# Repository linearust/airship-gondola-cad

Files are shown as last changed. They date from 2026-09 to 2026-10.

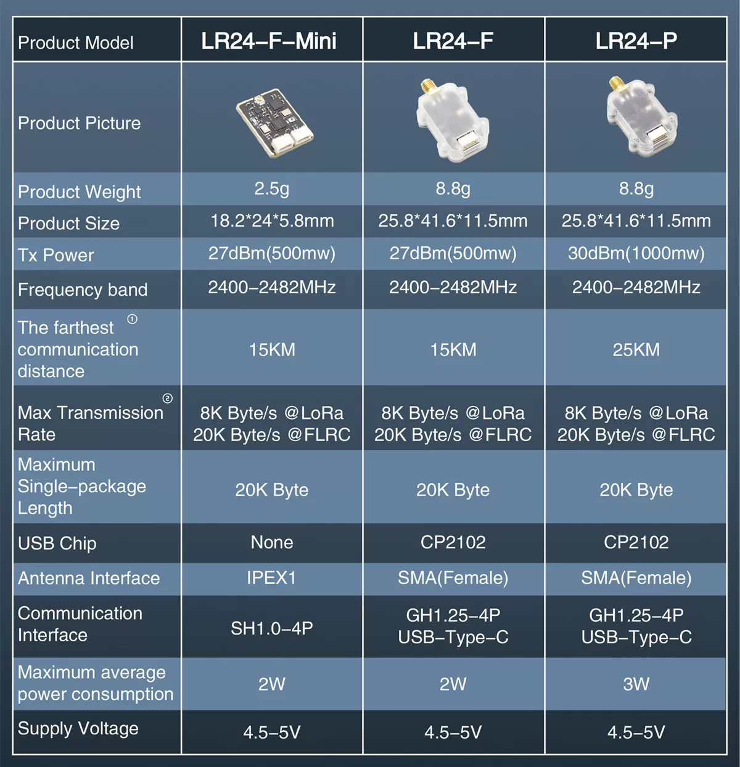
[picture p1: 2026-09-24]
references/lr24_specifications.webp

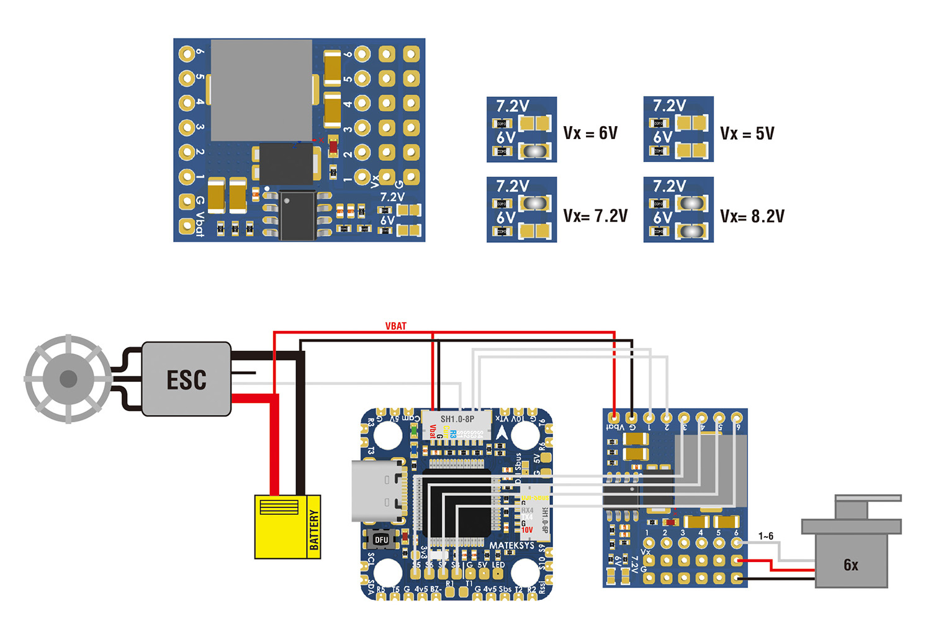
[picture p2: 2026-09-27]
references/matek_svpdb_8s_outputs.jpg

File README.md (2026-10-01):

# AI agent guide

Later user instructions take precedence. Inspect Git status and
`python3 -m gondola status` before editing; preserve unrelated edits and manual CAD.

## Design intent

- Favor low total mass and simple, printable, inspectable construction. Integrate
  parts unless assembly, motion or replacement benefits from separation.
- Prefer available metric parts, reusable interfaces and few fastener types.
  Accommodate fit variation without operating looseness or elaborate adjustment.
  Favor symmetric supports and snug located joints; nuts should insert freely
  while their pockets prevent rotation.
- Consider wiring, moving clearances, optical visibility and balance together.
  Improve existing geometry on merit, respecting confirmed purchases and intentional
  replaceable modules.

Scope: indoor LTA gondola, two independent tilt propulsors and onboard mounts;
fins and aft yaw hardware are excluded. Current manufacturing limits and selections
are in [design.py](gondola/contracts/design.py), not duplicated requirements here.

## State and evidence

[Contracts](gondola/contracts/), [parts](gondola/parts/) and
[assembly](gondola/assembly.py) define intended CAD, not measured hardware.
Read `release_status()` for unresolved interfaces. [Sources](references/sources.json)
index retained originals and dated user records. Distinguish source statements,
user confirmation, design allowances and measurements; resolve conflicts explicitly.
Preserve original evidence and provenance, not URLs alone. Keep changing dimensions
and generated inspection sheets out of maintained prose.

[Verification](references/design_verification.json) records a past execution, valid
only for its inputs. `source_fingerprint()` covers Python under `gondola`, root
macros and `gondola/data`; tests, tools and documents need separate change/hash checks.
CAD success does not establish physical fit, strength, creep, adhesion, wiring,
power, installed mass/CG or flight readiness. Qualify coupons using production
material, process, finish and feature orientation.

## Workflow

Update affected geometry, native controls/parents, interfaces, BOMs and motion/service
checks together. Review full travel and ordered removal; distinguish sampled from
continuous checks. Fixture replacement requires independent old/new shape, placement,
control and metadata review, never merely a new checksum to hide a failure.

Documentation-only changes: check links, JSON, source records and `git diff --check`.
Code changes: Ruff and relevant tests. CAD release: native FreeCAD unittest discovery
with no skips for `tests`, `tools/blender_review` and `tools/simulation`.
[Runtime launcher](gondola/freecad_runtime.py) locates the AppImage; use its
`AppRun python` with repository and `usr/lib` in `PYTHONPATH`.

Freeze source; run in order and stop on failure:

```sh
python3 -m gondola build
python3 -m gondola preview
python3 -m gondola compare
python3 -m gondola validate
python3 -m gondola bundle
python3 tools/blender_review/run.py --render-stills
python3 tools/simulation/export_parameters.py
```

`build/` is generated/ignored. Preview saves CAD, so it precedes file-bound checks.
Inspect assembly, print layout and affected views. For `gondola`, `--output-dir PATH`
precedes the subcommand; keep output/source paths consistent across tools. Export manifest-listed
parts, distinguish optional power parts, and retain hash-bound verification.

Optional paired rail/frame/saddle fit specimen: after validation, run
`python3 tools/fit_coupon/export_joint.py --output-dir PATH` with a new directory.
It crops saved production geometry; it is outside the installed BOM/print bundle
and tests local fit, not whole-frame strength or complete-assembly tool access.

Blender checks prescribed rigid motion, not dynamics or flexible wires. Simulation
geometry is exported to `build/simulation_parameters.json`; unknowns remain unset.
Native coordinates are not CV/CG or FRD. Recheck hashes before presenting artifacts.

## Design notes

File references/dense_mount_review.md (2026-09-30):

# Mounting interface source map

Plate geometry and permitted patterns are defined in
[mounting_plate.py](../gondola/parts/mounting_plate.py) and
[mounting_slots.py](../gondola/parts/mounting_slots.py); carrier support and
adhesive allocations are in [equipment_mounts.py](../gondola/parts/equipment_mounts.py).
Use the contracts and their checks when changing an occupied mount. This project
array is not a universal industry standard or a drop-in X500 interface.

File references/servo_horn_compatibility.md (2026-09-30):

# Horn source map

The [manufacturer provenance record](manufacturer/kst_x06_servo_horns_2026-09-28.json)
identifies the user-supplied archive, retained STEP, units and coordinate transform.
These are nominal source geometry, not measurements of a received horn.

Current selection and hole preparation belong to
[servo_horns.py](../gondola/contracts/servo_horns.py); adapter geometry and fit
allowances to [servo_coupling.py](../gondola/parts/servo_coupling.py).
Use [servo_module.py](../gondola/validation/servo_module.py) and
[horn_coupling.py](../gondola/validation/horn_coupling.py) for ordered
service checks.

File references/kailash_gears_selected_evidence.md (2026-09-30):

# Retained Kailash seller statements

Transcription from user-supplied saved AliExpress pages and dimension images.
The full product pages are not retained in this repository; this is seller
source evidence, not independent certification or a received-part measurement.
The [2026-09-29 cart](cart_selected_parts_2026-09-29.json) separately preserves
selected options and quantities. Links identify provenance, not live availability.

| Recorded item | 48T | 16T |
| --- | --- | --- |
| Listing | [HDAA-05](https://www.aliexpress.com/item/1005011637445325.html) | [XC05-S1](https://www.aliexpress.com/item/1005013121105173.html) |
| Selected option | 48 teeth / 3 mm | 16 teeth / 3 mm |
| Module / pressure angle | 0.5 / 20° | 0.5 / 20° |
| Tooth type / process stated | External spur / hobbing | External spur / hobbing |
| Pitch / outside diameter | 24 / 25 mm | 8 / 9 mm |
| Face width / total length | 3 / 8 mm | 5 / 10 mm |
| Hub diameter / extension beyond teeth | 12 / 5 mm | 6.5 / 5 mm |
| Plain bore | Ø3 mm; H8 stated | Ø3 mm; tolerance not stated |
| Radial screw thread | M3 | M3 |
| Screw axis from hub end | Not stated | 2.5 mm |
| Material wording | Aluminium alloy in description; alloy steel in attribute | Copper/copper alloy; exact alloy unspecified |

The page's 38.7 g example refers to 130T, not 48T. No measured masses, screw
inclusion, length, point or tightening torque are established by this record.
The 16T axial screw position must not be inferred for the 48T gear.

Retained source images: [section](kailash_16t_dimensions.png) and
[size table](kailash_16t_table.png). The section is generic; the 16T row gives
C=8, D=9 and G=6.5 mm. [Source index](sources.json) binds their retained bytes.
Current CAD interpretation belongs to [drive.py](../gondola/contracts/drive.py).

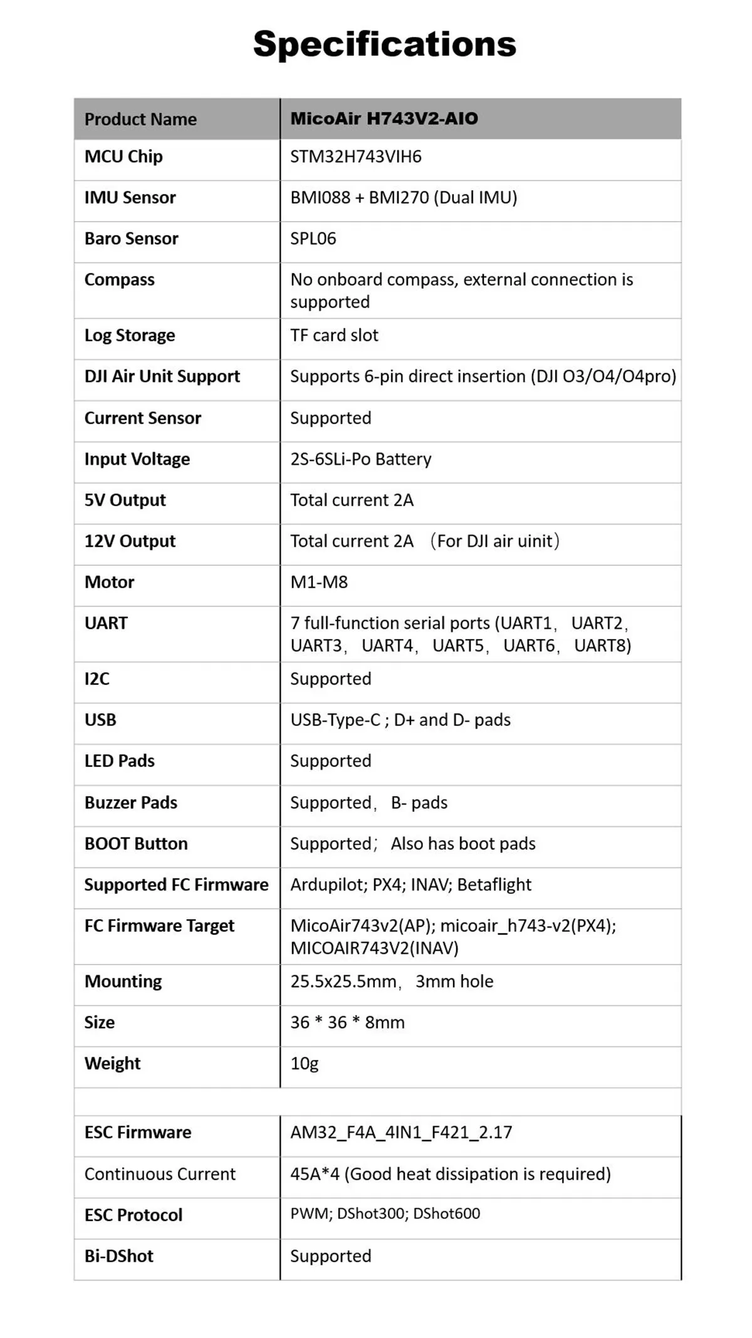
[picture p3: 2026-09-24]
references/micoair743v2_aio45a_specifications.webp

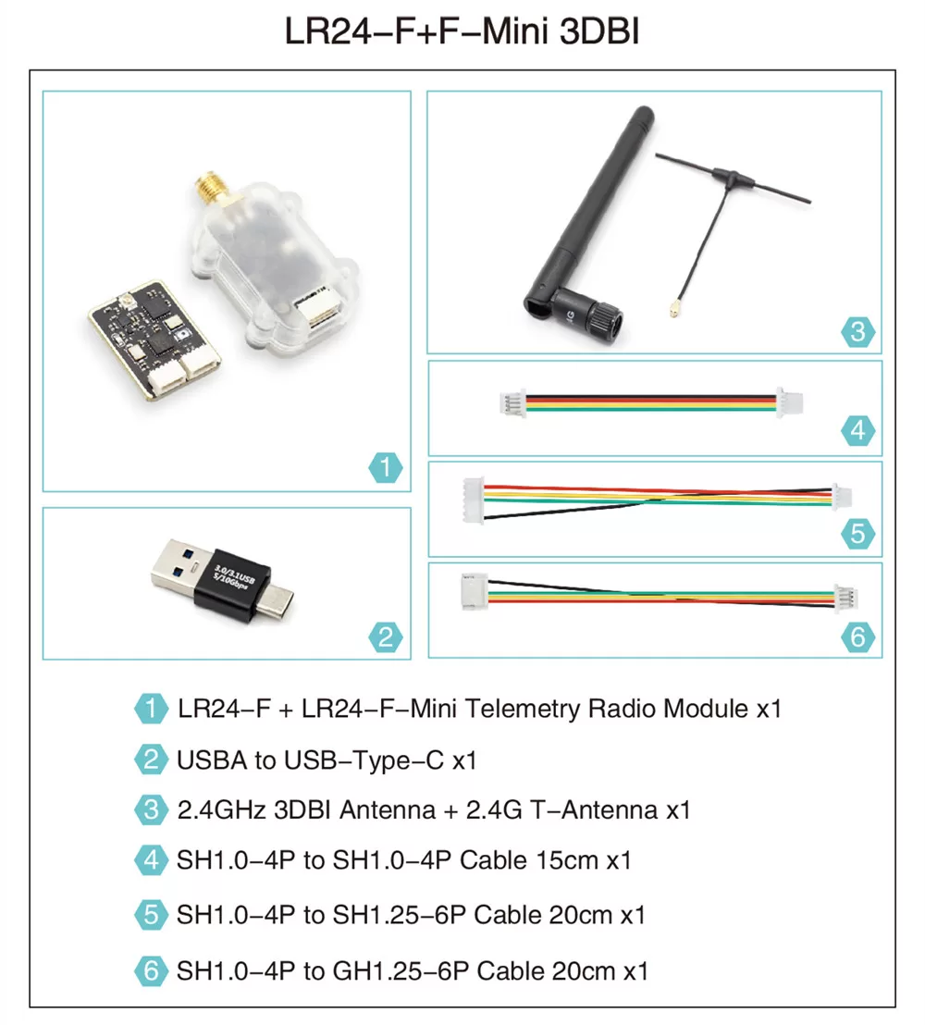
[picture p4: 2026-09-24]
references/lr24f_mini_package.webp

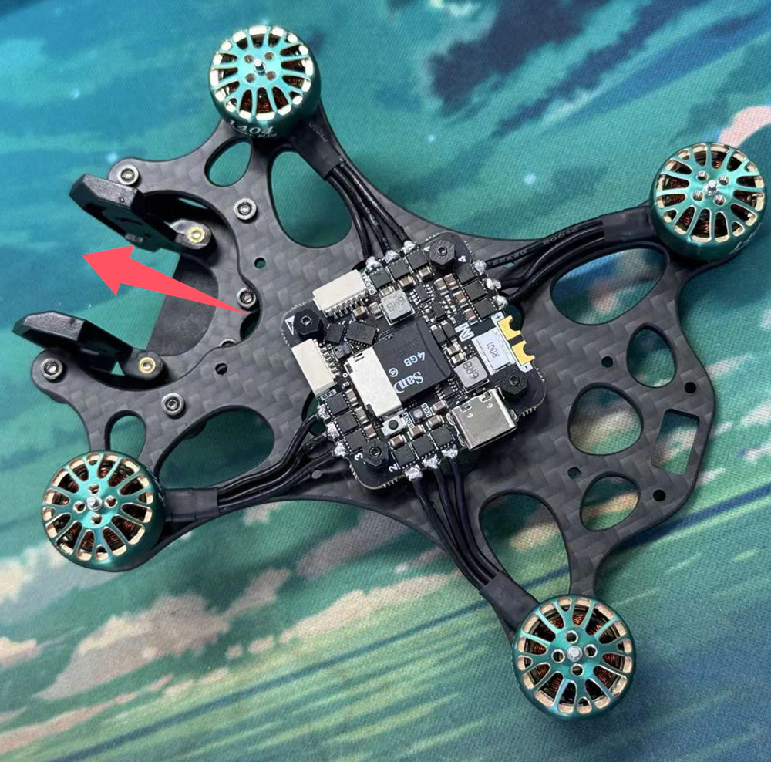
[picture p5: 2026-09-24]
references/micoair743v2_aio45a_orientation.webp

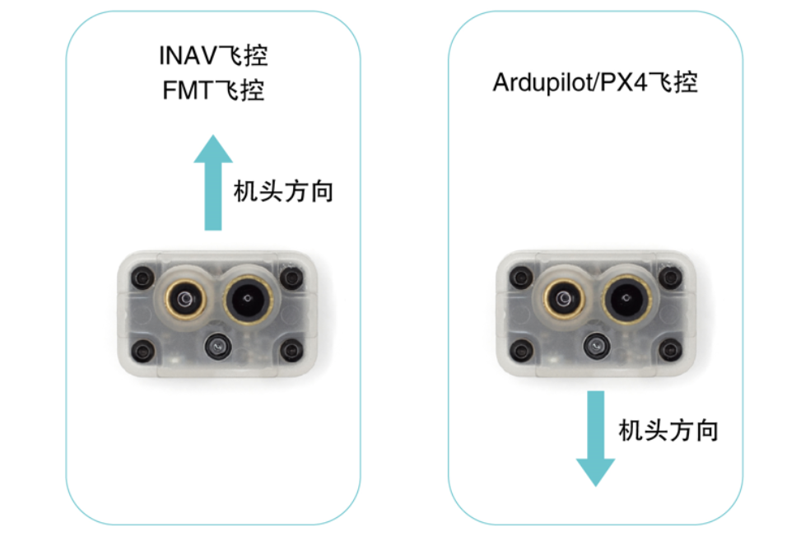
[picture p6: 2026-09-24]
references/mtf01p_orientation.webp

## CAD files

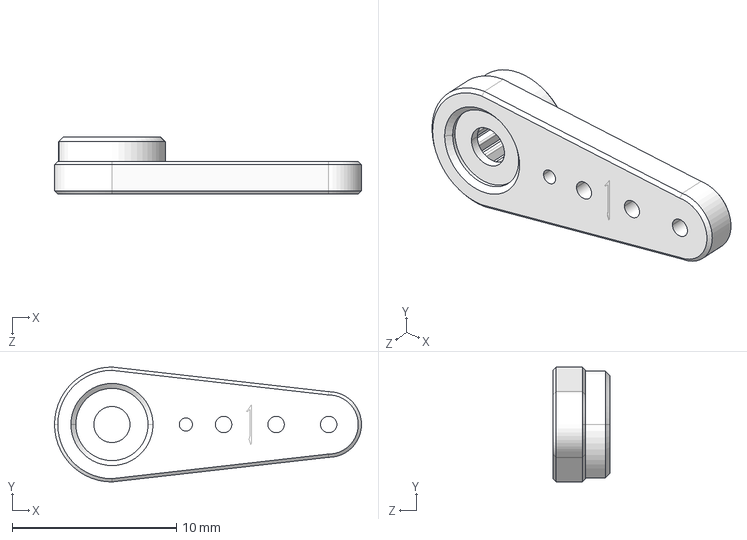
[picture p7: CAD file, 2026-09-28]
gondola/data/kst_x06_half_arm_1.step
18.7 x 7.00 x 3.50 mm

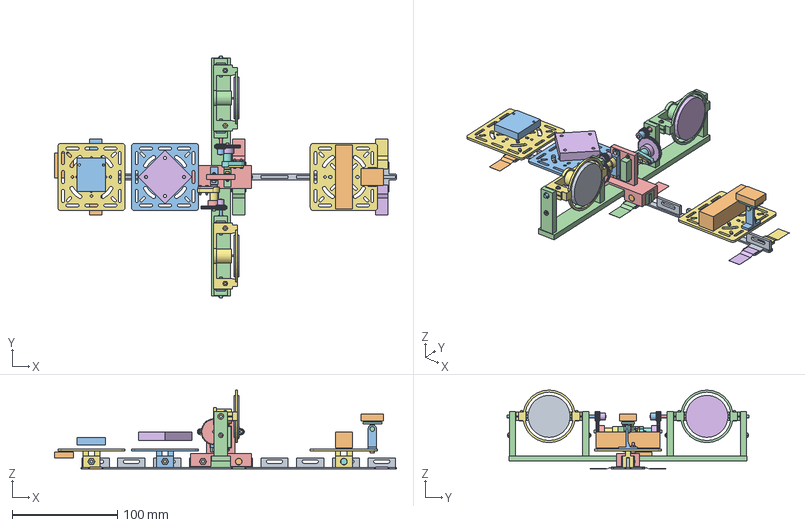
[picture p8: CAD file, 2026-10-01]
tests/fixtures/geometry.FCStd
325.1 x 230.0 x 75.0 mm
SLS/MJF | PA12 unfilled | PRINT | side-slot rail 300mm
REFERENCE | optional single-sided tape over wing
REFERENCE | optional single-sided tape over wing001
REFERENCE | optional single-sided tape over wing002
REFERENCE | optional single-sided tape over wing003
REFERENCE | optional single-sided tape over wing004
REFERENCE | optional single-sided tape over wing005
SLS/MJF | PA12 unfilled | PRINT | OpticalSensorTray
BUY | manual optical pitch nut
MTF-02P | independently leveled optical face
SLS/MJF | PA12 unfilled | PRINT | OpticalMountBase
BUY | manual optical pitch bolt
BUY | optical carrier foot 2 bolt
BUY | optical carrier foot 2 nut
SLS/MJF | PA12 unfilled | PRINT | Universal carrier | battery
BUY | M3 x10 recessed side rail bolt | design head envelope
BUY | M3 rail hex nut | blind pocket on a printed bearing floor
REFERENCE | provisional2S battery, long axisY
SLS/MJF | PA12 unfilled | PRINT | Universal carrier | electronics
BUY | M3 x10 recessed side rail bolt | design head envelope001
BUY | M3 rail hex nut | blind pocket on a printed bearing floor003
REFERENCE | MicoAir743v2-AIO-45A
SLS/MJF | PA12 unfilled | PRINT | Universal carrier | accessory
BUY | M3 x10 recessed side rail bolt | design head envelope002
BUY | M3 rail hex nut | blind pocket on a printed bearing floor004
REFERENCE | LR24-F-Mini | onboard radio
REFERENCE | LinkTrack P-AS | interchangeable navigation slot
SLS/MJF | PA12 unfilled | PRINT | PropulsionFixedFrame
SLS/MJF | PA12 unfilled | PRINT | ServoDriveBridge
BUY | PortDriverGear
BUY | PortServoHorn
SLS/MJF | PA12 unfilled | PRINT | PortHornGearAdapter
BUY | PortHornGearClampNearBolt
BUY | PortHornGearClampNearNut
BUY | PortHornGearClampFarBolt
BUY | PortHornGearClampFarNut
BUY | PortInputShaft
BUY | PortInputShaftClampBolt
BUY | PortInputShaftClampNut
BUY | PortServoEarLowerBolt
BUY | PortServoEarLowerNut
BUY | PortServoEarUpperBolt
BUY | PortServoEarUpperNut
KST X06 V6.0 vertical case 20×7×16.6; 6 g
BUY | StarboardDriverGear
BUY | StarboardServoHorn
SLS/MJF | PA12 unfilled | PRINT | StarboardHornGearAdapter
BUY | StarboardHornGearClampNearBolt
BUY | StarboardHornGearClampNearNut
BUY | StarboardHornGearClampFarBolt
BUY | StarboardHornGearClampFarNut
BUY | StarboardInputShaft
BUY | StarboardInputShaftClampBolt
BUY | StarboardInputShaftClampNut
BUY | StarboardServoEarLowerBolt
BUY | StarboardServoEarLowerNut
BUY | StarboardServoEarUpperBolt
BUY | StarboardServoEarUpperNut
KST X06 V6.0 vertical case 20×7×16.6; 6 g001
SLS/MJF | PA12 unfilled | PRINT | PortMotorCarrier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

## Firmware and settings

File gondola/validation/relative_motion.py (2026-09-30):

"""Continuous separation of installed solids belonging to different tilt groups."""

import math

from gondola.cad import belongs_to_group, world_shape
from gondola.contracts import servo_horns
from gondola.contracts.design import MODULE_STATIONS
from gondola.contracts.drive import drive_for_document

from .geometry import intersection_volume
from .rotation_envelope import full_orbit_envelope

MINIMUM_GAP_MM = 0.1
TOL = 1e-7


def _input_drive_membership(parts):
    """Require the selected metal-stub mechanism to share each input motion."""
    suffixes = (
        "ServoHorn",
        "DriverGear",
        "HornGearAdapter",
        "HornGearClampNearBolt",
        "HornGearClampFarBolt",
        "InputShaft",
        "InputShaftClampBolt",
        "InputShaftClampNut",
    )
    rows = []
    for prefix in ("Port", "Starboard"):
        expected = {prefix + suffix for suffix in suffixes}
        if not servo_horns.profile(side=prefix).threaded:
            expected.update(
                prefix + "HornGearClamp" + side + "Nut" for side in ("Near", "Far")
            )
        actual = {
            part["name"] for part in parts if part["group"] == prefix + "InputDrive"
        }
        rows.append(
            {
                "group": prefix + "InputDrive",
                "expected_parts": sorted(expected),
                "actual_parts": sorted(actual),
                "passed": actual == expected,
            }
        )
    return rows


def _static_expression_contract(doc, spec):
    """Allow only the source architecture's closed, manual-control dependencies.

    The four tilt formulas are the only expressions depending on the pod motion.
    Every other permitted formula reads literal manual properties. Inspecting
    *all* expression engines also rejects an expression added to one of those
    input properties, an intervening group, or an indirect helper object. A
    finite pose probe cannot establish this absence of nonlinear dependence.
    Static placements without expressions remain valid, including a moved root.
    """
    allowed = {}
    for station in MODULE_STATIONS:
        allowed[station.object_name] = {
            "Placement.Base.x": "RailPositionX",
        }
    allowed["OpticalFlowModule"] = {
        "Placement.Base.x": "MountSide==0?27mm:-27mm",
        "Placement.Rotation.Angle": "MountSide==0?0deg:180deg",
    }
    for prefix in ("Port", "Starboard"):
        allowed[prefix + "Pod"] = {
            "Placement.Rotation.Angle": "min(MaximumTilt;max(MinimumTilt;Tilt))"
        }
        allowed[prefix + "InputDrive"] = {
            "Placement.Rotation.Angle": f"-{prefix}Pod.Placement.Rotation.Angle/{spec.ratio:g}"
        }
    for coordinate in ("Roll", "Pitch"):
        allowed["Optical" + coordinate + "Stage"] = {
            "Placement.Rotation.Angle": f"min(MaximumAngle;max(MinimumAngle;{coordinate}))"
        }
    allowed["ModuleBatteryEnvelope"] = {
        "Placement.Base.x": "CentreX-(Length*cos(InPlaneRotation)-Width*sin(InPlaneRotation))/2",
        "Placement.Base.y": "CentreY-(Length*sin(InPlaneRotation)+Width*cos(InPlaneRotation))/2",
        "Placement.Base.z": "BottomZ",
        "Placement.Rotation.Angle": "InPlaneRotation",
    }
    count = 0
    for obj in doc.Objects:
        for path, expression in getattr(obj, "ExpressionEngine", ()):
            path = path.lstrip(".")
            if allowed.get(obj.Name, {}).get(path) != "".join(expression.split()):
                raise ValueError(
                    "Native motion expression contract rejects " + obj.Name + "." + path
                )
            count += 1
    return {
        "checked_expression_count": count,
        "scope": "Closed source expression allowlist across every native object. Additional expressions on manual controls, child features, intervening groups or indirect helper properties are rejected; static placements are allowed.",
        "passed": True,
    }


def _gap(first, second):
    return max(first[0] - second[1], second[0] - first[1], 0.0)


def _part(shape, name, *, group="Fixed", prefix="", axis=(0, 0, 0), rate=0.0):
    bounds = shape.BoundBox
    limits = [
        (bounds.XMin, bounds.XMax),
        (bounds.YMin, bounds.YMax),
        (bounds.ZMin, bounds.ZMax),
    ]
    envelope, radius, orbit = shape, 0.0, limits
    if rate:
        envelope, evidence = full_orbit_envelope(shape, axis)
        radius = evidence["radius_mm"]
        orbit = [
            (axis[0] - radius, axis[0] + radius),
            limits[1],
            (axis[2] - radius, axis[2] + radius),
        ]
    return dict(
        shape=shape,
        name=name,
        group=group,
        prefix=prefix,
        axis=axis,
        rate=rate,
        bounds=limits,
        envelope=envelope,
        radius=radius,
        orbit=orbit,
    )
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

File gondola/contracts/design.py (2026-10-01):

"""User decisions and unresolved interfaces consumed by CAD and the CLI.

Part geometry belongs to gondola/parts; published interface dimensions belong to
the other contract modules. Geometric test success never changes release status.
"""

import math
from collections import Counter
from dataclasses import asdict, dataclass
from numbers import Real

from .drive import SELECTED_DRIVE
from .equipment_interfaces import (
    FC_ELECTRICAL_EVIDENCE,
    FC_LISTED_MASS_G,
    FC_MODEL,
    X06_DATASHEET_SOURCE,
    X06_MANUFACTURER_SOURCE,
    flight_controller_contract,
)
from .equipment_options import get_navigation_profile, get_radio_profile
from .fasteners import KIT_MATERIAL, RAIL_FASTENER_MATERIAL
from .optical_sensors import get_sensor_profile
from .power_options import power_option_contract
from .rail_attachments import module_attachment_pattern
from .servo_horns import SELECTED_BY_SIDE
from .servo_horns import profile as horn_profile

CREALLO_GUIDE_URL = "https://creallo.com/ko/guide/design-spec-guide"
DESIGN_REVISION = "BY"
# Nominal local part dimensions, before print rotation; not delivered-size tolerance.
MAX_PRINT_PART_DIMENSION_MM = 340.0
# Chosen assembly length is independent of the supplier-screening size limit.
RAIL_LENGTH_MM = 300.0
# User's 2026-09-29 manufacturing review requires at least this nominal rail
# attachment thickness; actual delivered dimensions/curvature remain unmeasured.
RAIL_BASE_THICKNESS_MM = 1.5
# Project structural interface, independent of the FC mounting-hole pattern.
STACK_PITCH_MM = 45.0
STACK_ANCHOR_CENTRES = tuple(
    (sign * STACK_PITCH_MM / 2, sign * STACK_PITCH_MM / 2) for sign in (-1, 1)
)
STACK_ANCHOR_LOCATIONS = (
    " and ".join(f"({x:g}, {y:g})" for x, y in STACK_ANCHOR_CENTRES) + " mm"
)
PUBLISHED_PROCESS_SIZE_MM = {"SLS": [340, 340, 600], "MJF": [380, 380, 280]}
MANUFACTURING_DECISION = {
    "reviewed_on": "2026-09-30",
    "supplier": "Creallo",
    "material": "Unfilled PA12 design basis; supplier grade/process/finish agreement pending. Do not substitute fibre-filled grades without redesign and renewed flexure qualification.",
    "preferred_process": None,
    "candidate_processes": ["SLS", "MJF"],
    "maximum_nominal_part_dimension_mm": MAX_PRINT_PART_DIMENSION_MM,
    "part_size_rule": f"Each local part bounding-box dimension before print rotation and each oriented export dimension must be at most {MAX_PRINT_PART_DIMENSION_MM:g} mm. Apply to every installed print and coupon; additionally screen oriented exports against both published process envelopes. This nominal CAD limit is not a guarantee of delivered dimensions.",
    "nominal_rail_length_mm": RAIL_LENGTH_MM,
    "rationale": "PA12 is Creallo's documented functional powder-bed nylon and suits open integral supports and the rail flexure trial. Neither SLS nor MJF is established as superior for this assembly; choose with the supplier using fit, stiffness, straightness and mass requirements. A material/process change requires renewed fit and flexure qualification.",
    "supplier_process_policy": "Creallo integrates SLS/MJF quotations and selects the process unless separately agreed. No process is preselected here. Confirm the actual PA12 grade, process and finish before printing matched coupons and full parts.",
    "size_guide_scope": "Published maximum fabrication sizes include split-and-join manufacture. They are screening bounds, not guaranteed one-piece machine capacity or acceptance.",
    "qualification": "Not qualified: obtain one-piece acceptance and review rail flexures, straightness, curvature, fatigue and seated mounting fit. Use the same agreed unfilled PA12 process/material/finish and corresponding feature orientation for coupons and full parts. Verify the optical carrier foot and pitch seat for flatness, pointing stability and creep with actual fasteners.",
    "nominal_general_functional_wall_mm": 1.5,
    "nominal_rail_flexure_mm": RAIL_BASE_THICKNESS_MM,
    "flexure_exception": "The straight rail base and tape wings retain the user-reported manufacturing-review minimum of1.5mm nominal. Nine identical26mm walls on34mm centres leave8mm gaps above the continuous rail base. The16mm carrier feet retain full-foot travel of +/-4.2mm. The continuous58mm propulsion spine seats on adjacent walls;15.4mm slots permit +/-6mm paired trim with12mm centred load zones and at least19mm support per wall/45mm combined. The9walls retain5.3mm slot-end ligaments. Actual thickness, bonded curvature, tape retention, stiffness and fatigue remain unqualified; use the rail contract for exact intervals.",
    "dfam_basis": "Prefer simple integral load-bearing sections and accessible through-features. Retain openings for assembly, wiring or motion; omit lightening windows that leave fragile narrow ligaments for negligible system-level benefit. SLS/MJF powder supports overhangs; do not introduce splits solely from FDM/SLA support-angle rules. Keep powder-removal access to holes and pockets. Do not add lattice infill or sealed hollow regions; avoid extra fine struts and trapped powder.",
    "sources": {
        "dimensions_and_tolerances": CREALLO_GUIDE_URL,
        "process_policy": "https://creallo.com/ko/blog/posts/sls-mjf-integration-update",
        "process_capability": "https://creallo.com/ko/capability/process/3DP/SLS",
        "pa12_material": "https://creallo.com/ko/capability/material/SLS/SLSPA12",
        "design_guide": "https://creallo.com/ko/guide/3d-printing-design-guide",
        "lattice_and_powder_removal": "https://creallo.com/ko/guide/lattice-structure-3d-printing-dfam",
    },
}
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

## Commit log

2026-09-20 Refactor gondola CAD workflow and enforce artifact consistency
    Keep source, primary dimensional evidence and a pinned regression fixture; remove legacy generated trees. Consolidate part modules, CAD helpers, artifact hashing and schema definitions.
    Require current preview, saved-CAD validation and frozen-baseline comparison before packaging. Fix asynchronous preview failures, BOM evidence grouping and STL surface comparison across equivalent triangulations.
    Validated with 43 offline tests, Ruff and FreeCAD 1.1.3: full build/preview/validate/compare/bundle succeeds; all 90 baseline shapes and native controls are preserved.
    [rev_i_geometry.FCStd]
2026-09-20 Document procurement checklist for the current gondola assembly
    Record hardware specifications and installed quantities, onboard equipment, consumables and tools. Preserve unresolved OEM interfaces and require agents to synchronize the checklist with validated BO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
2026-09-20 Shorten rail to 340 mm for Creallo PA12 SLS prototype
    [design_contract.py]
2026-09-20 Lighten gondola with M2 hardware and add MTF-02P
    [rev_i_geometry.FCStd, rev_k_geometry.FCStd]
2026-09-20 Replace stacked boards with compact verified mounting interfaces
    [rev_k_geometry.FCStd, rev_l_geometry.FCStd]
2026-09-21 Fix journal retention and verify CAD procurement integrity
    [rev_l_geometry.FCStd, rev_m_geometry.FCStd]
2026-09-21 Reserve practical wiring access with minimal carrier changes
    [rev_m_geometry.FCStd, rev_n_geometry.FCStd]
2026-09-21 Add interchangeable optical sensor stack with verified clearances
    [rev_n_geometry.FCStd, rev_o_geometry.FCStd]
2026-09-21 Simplify ultralight gondola hardware and printed supports
    [rev_o_geometry.FCStd, rev_p_geometry.FCStd]
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2026-09-21 Organize design contracts and clarify CAD module naming
2026-09-21 Implement independent X06 geared tilt modules
    [rev_p_geometry.FCStd, rev_q_geometry.FCStd]
2026-09-21 Refactor propulsion builders and validation responsibilities
    Split geared propulsion assembly and audits into focused helpers while
    preserving native geometry, object order, metadata and motion expressions.
    Move portable purchasing specifications and manufacturing checks to their
    own modules, and keep malformed known specifications fail-closed.
    Retain the reviewed Rev Q fixture and all nominal dimensions, hardware
    quantities, mass accounting and manufacturing qualification limits.
2026-09-21 Improve connector access and centralize wiring checks
    Expand the FC peripheral allowance to 9 mm, move LR900 and P-AS 6 mm
    outward, and use a shared 44 mm structural stack. Add 2 mm side/top
    handling allowances to the radio and UWB connector lanes and relocate
    the XT30 allocation. Printed mass increases by 0.288 g with no change
    to purchased part types or quantities.
    Centralize wiring geometry and minimum-gap checks. Check tilted optical
    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
    [rev_q_geometry.FCStd, rev_r_geometry.FCStd]
2026-09-21 Support interchangeable tilt gears with a shared radial input mount
    Keep the 60/20 drive as default and support the sourced 64/20 alternative
    using the same printed frame, input supports, shafts and fastener inventory.
    Bind gear identity, native motion, placement, procurement and validation to
    one finite drive contract; retain explicit limits on clamp retention.
    Audit and pin the Rev S geometry transition. Verify cartridge adjustment,
    functional walls, and prerequisite-aware bearing-cap service. Distinguish
    STEP scalar integration drift from actual solid changes through bilateral
    empty-topology checks while retaining strict bounds and difference gates.
    [rev_r_geometry.FCStd, rev_s_geometry.FCStd]
2026-09-22 Refactor propulsion contracts and tighten print geometry validation
    Centralize required propulsion evidence so omitted checks cannot lower their
    own expected counts and a successful parent cannot hide failed rows. Remove
    unused constants, reuse the output-axis spacing, and derive manufacturing
    probes from the saved drive configuration.
    Use one print-solid identity gate for STEP round trips and repeated parts.
    Reject loose point, edge or face topology while allowing single-solid
    container wrappers and the verified empty-cut volume-integral exception.
    Validated with Ruff, 183 native tests (zero skips), full 60/20 and64/20
    assembly/equipment audits, and the unchanged151-shape RevS baseline.
    D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
2026-09-22 Replace adjustable gear mounts with fixed interchangeable supports
    Use round mounting holes and gear-specific 60T/64T input supports in the common frame. Remove the radial-slide travel and live mesh-adjustment controls; keep the servo cradle and bearing seats integral while retaining the detachable support needed for assembly and service.
    Validate the fixed datum, matching support identity and circular-hole geometry, including negative tamper tests. Preserve existing shaft, fastener, electronics, optical and rail geometry. Correct the lower horn-clamp extraction path for the 64T support and continuously check both sides of both configurations. Update the AI-agent contract and reviewed RevT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
    [rev_s_geometry.FCStd, rev_t_geometry.FCStd]
2026-09-22 Simplify propulsion to direct servo gears on an integral frame
    Replace input cartridges, shafts and bearings with bought KST horns and compact direct gear adapters. Integrate open-sided servo saddles into the fixed frame and use 7 mm bore driver gears. Preserve supported output stubs and ordered service access.
    Audit and pin Rev U geometry, update procurement and estimated mass, and validate both gear configurations. All 187 native tests and the build, preview, validate, compare and bundle workflow pass. Servo radial loading and physical adapter fit remain prototype qualification items.
    [rev_t_geometry.FCStd, rev_u_geometry.FCStd]
2026-09-22 Make servo gear drives replaceable on a common frame
    [rev_u_geometry.FCStd, rev_v_geometry.FCStd]
2026-09-22 Increase tilt fastener clearance and validate continuous motion
    [rev_v_geometry.FCStd, rev_w_geometry.FCStd]
2026-09-22 Strengthen replaceable servo holders with paired side walls
    [rev_w_geometry.FCStd, rev_x_geometry.FCStd]
2026-09-22 Make PA12 process selection neutral and enforce print part size limits
    [rev_x_geometry.FCStd, rev_y_geometry.FCStd]
2026-09-22 Integrate servo supports and simplify bearing retainers
    [rev_y_geometry.FCStd, rev_z_geometry.FCStd]
2026-09-22 Separate paired servo drive for replacement
    [rev_aa_geometry.FCStd, rev_z_geometry.FCStd]
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2026-09-22 Adapt gondola to selected cart gears, shafts and M2 hardware
    Use the supplied 48T/16T module-0.5 gear dimensions and both 3 mm
    bores. Couple the drivers through prepared metal input stubs, retain
    a removable paired-servo module, and account for asymmetric gear widths.
    Replace square-nut/headless rail clamps with the selected M2 button
    screws and hex nuts, including full release/tool access. Record the
    6061 rod cut list, generic bearing selection, exclusions and unverified
    received-part interfaces. Audit and pin revision AB geometry.
    [rev_aa_geometry.FCStd, rev_ab_geometry.FCStd]
2026-09-22 Refactor purchase metadata and propulsion service checks
    Share purchase field definitions across native CAD annotations and BOM
    exports. Read gear and fastener constants from their source contracts,
    make selected hardware materials explicit, and synchronize CAD scope
    exclusions with the selected equipment contract.
    Consolidate the input-drive part inventory and service-path dispatch
    without changing validation thresholds, evidence, or part geometry.
    Clarify the AI README and selected-hardware documentation.
    Validation: all 254 native FreeCAD tests pass without skips. Full saved-CAD
    validation, comparison of all 130 shapes against the unchanged AB fixture,
    and current-source prototype bundl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
    [design.py]
2026-09-23 Integrate optical tower and relax nonlocating fit envelopes
    [rev_ab_geometry.FCStd, rev_ac_geometry.FCStd]
2026-09-23 Replace optical tower fasteners with integral PA12 latches
    [rev_ac_geometry.FCStd, rev_ad_geometry.FCStd]
2026-09-23 Simplify bearing supports and reinforce optical pivots
    [rev_ad_geometry.FCStd, rev_ae_geometry.FCStd]
2026-09-23 Fix optical tower seating and audit servo horn clearance
    [rev_ae_geometry.FCStd, rev_af_geometry.FCStd]
2026-09-23 Simplify bearing and horn retention in revision AG
    Replace four printed bearing caps and their fasteners with inward-loaded cups,
    integral outer shoulders and four purchased inner-ring spacers. Remove the two
    horn backstraps using prepared stock horn tips and shared M1.6 fasteners.
    Preserve the removable paired servo drive and all selected gear/shaft sizes.
    Add capture, complete-rotor motion and staged service checks, document the new
    purchases and horn preparation, and audit the intentional fixture transition.
    Installed prints decrease from 18 to 12; modeled installed pieces from 84 to 74.
    Validation: 276 native tests without skips, 7 procurement tests after wording
    cleanup, final saved-C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
    [rev_af_geometry.FCStd, rev_ag_geometry.FCStd]
2026-09-23 Strengthen rail clamp and simplify bearing-post roots in AH
    [rev_ag_geometry.FCStd, rev_ah_geometry.FCStd]
2026-09-23 Simplify optical base and paired servo support in AI
    [rev_ah_geometry.FCStd, rev_ai_geometry.FCStd]
2026-09-23 Tighten rail fit and consolidate servo supports in AJ
    [rev_ai_geometry.FCStd, rev_aj_geometry.FCStd]
2026-09-23 Simplify horn adapters, servo bridge and P-AS support
    [rev_aj_geometry.FCStd, rev_ak_geometry.FCStd]
2026-09-23 Refactor shared propulsion service checks
    Separate removal paths and retained-obstacle collection from report coordination, removing circular validation imports. Reuse the common shape translation helper and remove unused horn helpers and constants.
    Validation: 311 native tests passed with no skips; build, preview, validate, compare and bundle passed. All 117 shapes, placements, native controls and interface metadata match the unchanged AK fixture. BOM and design metrics are unchanged.
2026-09-23 Reinforce optical pivot link and verify input nut capture
    [rev_ak_geometry.FCStd, rev_al_geometry.FCStd]
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2026-09-23 Remove bearing spacers and adapt drive to supplied servo horns
    [rev_al_geometry.FCStd, rev_am_geometry.FCStd]
2026-09-23 Refactor servo interfaces and correct bearing travel checks
    [equipment_interfaces.py]
2026-09-24 Rearrange gondola modules for rear FC wiring
    Place the independent electronics carrier behind the neutral motors and move the battery carrier to the opposite side. Preserve the transferable optical stack, detachable servo module and physical part inventory.
    Connect and validate motor-lead planning reserves, account for carrier yaw in clamp service checks, preserve the FC heading basis, and update the reviewed native fixture and Blender framing. Native regression suite: 362 tests passed; build, preview, assembly validation, baseline comparison and prototype bundle passed.
    [rev_am_geometry.FCStd, rev_an_geometry.FCStd]
2026-09-24 Share FC and P-AS equipment support paths
    [rev_an_geometry.FCStd, rev_ao_geometry.FCStd]
2026-09-24 Support interchangeable MicoAir optical sensors on one tray
    [rev_ao_geometry.FCStd, rev_ap_geometry.FCStd]
2026-09-24 Select 45A AM32 controller and centralize its interface evidence
    [rev_ap_geometry.FCStd, rev_aq_geometry.FCStd]
2026-09-24 Support interchangeable navigation and radio modules on shared carrier
    [rev_aq_geometry.FCStd, rev_ar_geometry.FCStd]
2026-09-25 Use factory-threaded servo horns with simple assembly clearance
    [rev_ar_geometry.FCStd, rev_as_geometry.FCStd]
2026-09-25 Compact electronics carrier and standardize on Mini radio
    [rev_as_geometry.FCStd, rev_at_geometry.FCStd]
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2026-09-27 Support interchangeable servo horns and optional power stacks
    [rev_at_geometry.FCStd, rev_au_geometry.FCStd]
2026-09-27 Simplify carrier plates and standardize optional power integration
    [rev_au_geometry.FCStd, rev_av_geometry.FCStd]
2026-09-27 Standardize equipment carriers and modular mounting interfaces
    [rev_av_geometry.FCStd, rev_aw_geometry.FCStd]
2026-09-27 Simplify common carriers and remove asymmetric radio tab
    [rev_aw_geometry.FCStd, rev_ax_geometry.FCStd]
2026-09-27 Redesign equipment carriers around the purchased carbon FC adapter
    Use a raised 16 mm saddle and independent 25.5 mm FC retention, compact role carriers, integral optical and optional power supports, and corrected wire clearances. Preserve the removable servo drive and 340 mm rail. Retain source-bound CAD/export audits and 448 passing native tests; physical fit and FC damping remain unqualified.
    [rev_az_geometry.FCStd]
2026-09-28 Standardize carbon mounting plates and rebuild the direct-clamp rail
    [rev_ba_geometry.FCStd]
2026-09-28 Restore printed rail and integral carriers from pre-carbon AX design
    [rev_az_geometry.FCStd, rev_ba_geometry.FCStd]
2026-09-28 Restore universal slotted printed mounts from AY checkpoint
    [rev_ax_geometry.FCStd, rev_ay_geometry.FCStd]
2026-09-28 Use square slotted carriers and compact single-axis optical mount
    [rev_ay_geometry.FCStd, rev_bb_geometry.FCStd]
2026-09-28 Refactor shared mounting geometry without changing BB design
    Centralize plate geometry and optical upright construction, remove redundant helpers and cuts, and clarify agent documentation. Preserve the pinned BB fixture; retain 455 passing native tests and exact main/optional CAD equivalence evidence.
2026-09-28 Consolidate agent requirements and workflow into README
    Remove the separate handoff, distinguish persistent user requirements from current design choices, and correct superseded horn guidance. Documentation only: independent requirements review, 72 local links and native command syntax checked; source, pinned fixture and saved CAD hashes remain unchanged.
2026-09-28 Condense and verify the AI agent guide
    Reduce README by 36.6 percent while preserving user requirements, current selections and unresolved boundaries. Clarify the dual SLS/MJF envelope screen and standard-part sourcing. Reviewed against source contracts; 26 local links and native command syntax checked. CAD source, fixture and saved artifacts are unchanged.
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2026-09-28 Simplify servo seating and reuse carrier for tether power
    [rev_bb_geometry.FCStd, rev_bc_geometry.FCStd]
2026-09-28 Improve rail tape support and integral carrier posts
    [rev_bc_geometry.FCStd, rev_bd_geometry.FCStd]
2026-09-28 Use manufacturer X06 half-arm geometry and compact coupling
    Select the supplied half arm 1 and retain the original STEP and archive.
    Replace the former universal horn interface with two short tolerance slots,
    prepared factory holes and rear M1.4 screws with front nuts. Preserve
    removable servo modules and the existing input shaft and gear datums.
    Bound intentional spline-envelope contact without hiding case collisions.
    Update ordered service checks, procurement, native controls and Blender
    review metadata. Archive independent geometry and fixture-transition review.
    Validation: 524 native tests, zero skips; ordered build, preview, compare,
    validate and bundle pass; seven Blender scenes and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
    [kst_x06_half_arm_1.step, kst_x06_servo_horns_2026-09-28.json, rev_bd_geometry.FCStd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]
2026-09-29 Refine horn registration, mounting slots and centreline optical support
    [rev_be_geometry.FCStd, rev_bf_geometry.FCStd]
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2026-09-29 Set actual 150 mm propulsion span and 50 mm pivot height
    [rev_bf_geometry.FCStd, rev_bg_geometry.FCStd]
2026-09-29 Simplify optical mounting and strengthen output shaft support
    Mount the optical tray on a direct rail shoe with one pitch joint, add a
    protected central M2 attachment to the universal carrier, and taper the OEM
    horn adapter while preserving its round-hole/short-slot tolerance interface.
    Move the existing output bearings nearer the gears, lengthen shaft grips,
    and strengthen the straight supports without adding bearing hardware.
    Refresh native controls, geometry fixtures, BOMs and simulation/Blender exports.
    Record 543 passing native tests, 25 focused Blender tests after its inventory
    correction, and final saved-CAD/print/assembly verification with explicit scope.
    [rev_bg_geometry.FCStd, rev_bh_geometry.FCStd]
2026-09-29 Mount optics on universal carriers and rebalance output supports
    Replace the separate optical rail shoe with a two-bolt carrier foot. Preserve the 150 mm main-axis spacing and 50 mm height, use a 70 mm bearing span, and check space and removal paths for a future replacement rotor.
    Refresh the BI native fixture, simulation snapshot and evidence. Final coverage comprises 563 native tests across 56 modules, including full reruns of two corrected test setups; saved CAD, manufacturing exports, optional layouts and six Blender scenes pass validation. Record the PA12 preliminary quotation package and quantities.
    [rev_bh_geometry.FCStd, rev_bi_geometry.FCStd]
2026-09-29 Refactor OEM horn service checks and record confirmed 2S support
    [rev_bi_geometry.FCStd]
2026-09-29 Replace bearing latches with serviceable bolted keepers
    [rev_bj_geometry.FCStd]
2026-09-29 Refine rail manufacturing and frame access; retain current evidence
    [geometry.FCStd, rev_bi_geometry.FCStd, rev_bj_geometry.FCStd]
2026-09-29 Simplify and lighten the rail with a compact verified layout
    [geometry.FCStd]
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2026-09-30 Simplify optical mount with an integral locator and one foot clamp
    [geometry.FCStd]
2026-09-30 Replace T clamps with a lightweight side-bolted slotted rail
    [geometry.FCStd]
2026-09-30 Improve rail flexibility with smooth constant-thickness waists
    [geometry.FCStd]
2026-09-30 Distribute rail flexure across eight gaps and nine mounting walls
    [geometry.FCStd]
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2026-09-30 Standardize rail sections and share propulsion mounting clamp
    [geometry.FCStd]
2026-09-30 Strengthen modular rail joints with recessed M3 U mounts
    [geometry.FCStd]
2026-09-30 Brace propulsion rail joints with opposed M3 clamps and a U saddle
    Seat the replaceable servo saddle on broad faces and two short side guides. Share two M3x12 pairs with adjacent rail walls, retaining 150 mm propulsor spacing and 50 mm height. Update paired hardware, wire approach, saved controls and complete removal sequences.
    Validation: 644 native tests without skips, independently reviewed fixture transition, all seven release stages, 13 print SKUs and six Blender scenes. Nominal structural/hardware mass increases by 4.50 g; physical fit and loaded retention remain unqualified.
    [geometry.FCStd]
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2026-09-30 Use load-bearing U sections for shared rail and servo joints
    Replace short guides and open nut windows with continuous U walls and
    blind nut pockets. Preserve module separation and fastener count, update
    bolt lengths, and raise common carriers while preserving wiring and optical
    clearances. Strengthen geometry, service-path and regression checks.
    Verified with 671 native tests, the complete CAD/export/Blender/simulation
    pipeline, independent fixture review and refreshed paired fit coupons.
    [geometry.FCStd]
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2026-10-01 Reinforce bearing post roots with integral planar tapers
    [geometry.FCStd]
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2026-10-01 Seat rail mounts and simplify propulsion supports
    [geometry.FCStd]
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2026-10-01 Refine bearing keepers and recessed nut seats
    Extend keeper backing, simplify motor carriers into flat shaft-clamp blocks, and recess the horn, optical and servo-ear nut seats. Preserve purchased hardware and the 12 mm propeller-plane datum.
    Increase the optical foot end stock, verify ordered fastener removal, and bind the reviewed fixture and release artifacts to native checks.
    [geometry.FCStd]
2026-10-01 Improve mounting symmetry, fit allowances and propulsor support
    Use symmetric carrier legs and centred supports, recess keeper nuts,
    and tighten only locating interfaces while preserving free nut insertion.
    Move the nominal propeller plane to 15 mm with a 3 mm motor plate and
    inboard guard connections that preserve full-rotation metal clearance.
    Retain purchased interfaces and fastener inventory; update native checks,
    review the saved geometry independently, and regenerate release evidence.
    [geometry.FCStd]
